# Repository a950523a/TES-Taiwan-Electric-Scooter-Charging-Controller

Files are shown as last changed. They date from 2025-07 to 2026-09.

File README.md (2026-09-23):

# TES-0D-02-01 DC Charger Controller

> 專為 TES-0D-02-01 標準設計的開源電動機車直流充電控制器。  
> 基於 ESP32-S3，使用 ESP-IDF 原生開發，支援 Web UI 監控、REST API 及 OTA 無線更新。






---

> 🛒 **現成品與服務**：iE125 原廠充電器改裝、TES 快充控制板 —— 見 **[海龜電能官網](https://a950523a.github.io/)**。

---

## ⚠️ 免責聲明與安全警告

**本專案僅包含「控制板」的軟硬體設計，不包含功率級電源模組。**

1. **高壓危險**：本控制器需配合高壓直流電源使用，組裝與測試過程存在觸電與火災風險。
2. **非商業產品**：本專案為個人研究與技術驗證性質，未經 BSMI、UL 等安規認證。
3. **責任歸屬**：使用本專案所產生的任何後果（包括但不限於車輛損壞、電池故障、人身傷害），**使用者需自行承擔**。若不具備相關電學知識，請勿嘗試製作。
4. **BMS 風險**：CAN Bus 線路若接線錯誤或短路，**將導致車輛 BMS 永久性損壞**，請務必在低壓環境確認無誤後再上機。

---

## 🎯 專案範圍

本 Repository 專注於 **TES 協議控制邏輯** 的實作。

- **包含**：ESP32-S3 控制韌體、CAN Bus 通訊、狀態機邏輯、Web UI、OTA 更新
- **不包含**：功率級整流器、AC/DC 電源模組的控制碼（請依據選用的電源模組自行適配）

---

## ✨ 功能特點

### 核心協議
- **TES 標準相容**：完整實作 TES-0D-02-01 充電通訊協議（0x500/501/508/509/5F0/5F8）
- **寬範圍支援**：最高支援 120V / 100A (12 kW)
- **通用性**：適用於 eMoving iE125 ZAU ES-2000 等支援 TES 快充標準之車輛

### 智慧功能
- **Web UI / PWA**：內建單頁應用，1 秒即時更新電壓、電流、SOC、剩餘時間；可安裝至手機桌面
- **REST API**：`GET /status`、`POST /start`、`POST /stop`、`POST /ota`
- **mDNS**：連接 WiFi 後可用 `http://tes-charger.local` 直接存取
- **OTA 無線更新**：Web UI 一鍵從 GitHub Releases 拉取最新韌體，自動重刷
- **MQTT 遠端監控**：設定 broker 後可在任何網路環境即時監控並遠端 Start/Stop
- **Cloud PWA**：無需與設備在同一個 WiFi，透過 MQTT 遠端監控 👉 [monitor.html](https://a950523a.github.io/TES-Taiwan-Electric-Scooter-Charging-Controller/monitor.html)
- **推播通知**：充電開始／完成／故障時自動透過 ntfy 或 Webhook 推播到手機
- **充電紀錄**：最近 20 次充電的時長、電量 (Wh)、SOC 起訖、停止原因
- **OLED 狀態顯示**：SSD1306 128×64，顯示充電狀態、電壓電流、SOC、剩餘時間
- **設定選單**：長按 SETTING 進入，可調最大電壓、電流、目標 SOC、WiFi 設定
- **LuxBeacon**：LED SOC 脈衝燈號編碼

### 架構特點（V3 重構）
- **純 C99 狀態機**（`tes_protocol/`）：零平台依賴，可移植至 STM32 或 PC 單元測試
- **HAL 抽象層**：硬體相關程式碼全部隔離在 `charger_hal/` 和 `drivers/`
- **GitHub Actions CI/CD**：推送 tag 自動編譯並建立 Release

---

## 🚀 安裝韌體

### 方法一：瀏覽器一鍵燒錄（推薦，無需安裝任何工具）

使用 Chrome 或 Edge，前往 👉 **[GitHub Pages 燒錄工具](https://a950523a.github.io/TES-Taiwan-Electric-Scooter-Charging-Controller/)**

USB 連接主板，點「開始安裝」，全程自動完成（約 30–60 秒）。

### 方法二：命令列燒錄

從 [Releases](https://github.com/a950523a/TES-Taiwan-Electric-Scooter-Charging-Controller/releases/latest) 下載 `tes_charger_flash.bin`：

```bash
esptool.py --chip esp32s3 -p <PORT> write_flash 0x0 tes_charger_flash.bin
```

### 方法三：OTA 更新（已有 V3 韌體）

連線至設備 Web UI → 點「更新至最新韌體」→ 自動從 GitHub Releases 下載並重刷。

---

## 📶 初次設定 WiFi

燒錄完成後：

1. 用手機或電腦連接 WiFi：`TES-Charger`（無密碼）
2. 瀏覽器開啟 `http://192.168.4.1`
3. 在「設定」填入家用 WiFi SSID 與密碼 → 儲存
4. 重啟後自動連接，之後使用 `http://tes-charger.local`

---

## 📱 遠端監控

### 裝置端 PWA（同一個 WiFi）

連線至 `http://tes-charger.local`，點瀏覽器「加入主畫面」即可安裝為 PWA。

### Cloud PWA（任何網路）

👉 **[https://a950523a.github.io/.../monitor.html](https://a950523a.github.io/TES-Taiwan-Electric-Scooter-Charging-Controller/monitor.html)**

需先在裝置端 Web UI 設定 MQTT Broker（建議使用免費公共 broker：`mqtt://broker.hivemq.com:1883`）。
設定後點「取得遠端監控連結」，掃描 QR code 或複製連結，在任何地點開啟即可即時監控並遠端 Start/Stop。

---

## 🕹️ 操作說明

| 按鈕 | 待機 | 選單導覽 | 選單編輯 |
|---|---|---|---|
| START | 開始充電 | 上一項 | 微調 +0.1 / 長按 +1 |
| STOP | 停止充電 | 下一項 | 微調 −0.1 / 長按 −1 |
| SETTING 短按 | 循環 SOC 預設 (80→95→100%) | 確認 / 進入編輯 | 確認，回到導覽 |
| SETTING 長按 | 開啟設定選單 | — | — |
| EMERGENCY | 緊急停止（任何狀態有效） | 同左 | 同左 |

---

## 🛠️ 硬體設計

- **原理圖 / PCB**：`docs/PCB/` 目錄
- **BOM**：`docs/BOM_V2/` 目錄
- **主要元件**：ESP32-S3 N16R8、ADS1115、SSD1306 OLED、CAN Transceiver、繼電器模組

硬體設計以通用性為核心，亦適合使用萬用板手工搭建。

---

## 💻 開發環境（ESP-IDF）

```powershell
# 設定環境（Windows）
$env:IDF_PATH = "C:\Users\<user>\esp\v5.5.1\esp-idf"
# 詳見 CLAUDE.md 完整 PATH 設定

# 編譯
cd v3
idf.py build

# 燒錄
idf.py -p <PORT> flash monitor
```

詳細架構說明、任務設計、IPC 機制請參閱 [CLAUDE.md](CLAUDE.md)。

---

## 🤝 社群與支援

- **服務與洽詢**：[海龜電能官網](https://a950523a.github.io/)・[Facebook 粉專](https://www.facebook.com/profile.php?id=61582382523577)（iE125 原廠充電器改裝、TES 快充控制板）
- **Facebook 社群**：[TES 電動機車充電技術交流](https://www.facebook.com/groups/791962053528872/?ref=share&mibextid=NSMWBT)
- **問題回報**：[GitHub Issues](https://github.com/a950523a/TES-Taiwan-Electric-Scooter-Charging-Controller/issues)

---

## ⚖️ 授權

### 著作權

本專案的程式碼與設計檔案採用 **[CC BY-NC-SA 4.0](https://creativecommons.org/licenses/by-nc-sa/4.0/deed.zh_TW)** 授權。

- ✅ 分享與改作：需標示原作者，並以相同條款釋出
- 🚫 禁止商業使用：不得將本專案之設計圖檔、程式碼用於商業量產或販售營利

### 專利權不在本授權範圍內

CC BY-NC-SA 4.0 **只授權著作權，不授權專利權**。這不是本專案額外附加的限制，
而是授權條款本文第 2(b)(2) 節的明文規定（見 [`LICENSE.md`](LICENSE.md) 第 52 行）：

> Patent and trademark rights are not licensed under this Public License.
>
> （本公眾授權條款不授權專利權與商標權。）

因此，依 CC BY-NC-SA 4.0 使用本專案者，僅取得著作權範圍內之授權。**如需商業
使用授權，請另行聯絡作者。**

Copyright (c) 2025-2026 Chris Huang.
All rights not expressly granted under the above license are reserved.

---

## 📌 專案紀錄

| 階段 | 時間 | 內容 |
|---|---|---|
| 專案開始 | 2025-06-19 | Arduino 原型 |
| V2 系列 | 2025-10 ~ 2025-12 | PlatformIO / C++，v2.4.0 ~ v2.5.0-beta |
| **V3 重構** | 2026-05-02 | 改用 ESP-IDF 原生 C99，協定層抽成零相依模組 |
| 遠端監控 | 2026-05 ~ 2026-09 | MQTT、Cloud PWA、排程充電、ESP-NOW PSU 傳輸 |
| 最新釋出 | 2026-09-10 | v3.5.0，**實車驗證完整充電流程** |
| 硬體 V1.3 | 2026-09 | 由 EasyEDA Pro 遷移至 KiCad，改為工具鏈可重現、可驗證 |

技術範圍涵蓋：TES-0D-02-01 協定狀態機、CAN Bus 通訊、即時 FreeRTOS 任務架構、
電源模組控制（UART／ESP-NOW 雙傳輸）、Web UI／REST API／PWA、OTA 更新、
以及 PCB 設計與驗證工具鏈。

作者：**Chris Huang**（[@a950523a](https://github.com/a950523a)）

---

## 🔗 相關專案

- **[TES-Protocol](https://github.com/a950523a/TES-Protocol)**：本專案抽出的可攜式 C99 CAN codec（`tes_types.h` + `tes_codec.c`），可作為 submodule 用於 STM32 或其他平台
- **[LianMing-PSU-Controller](https://github.com/a950523a/LianMing-PSU-Controller)**：聯明電源 CAN Bus 控制器，可與本專案配合使用實現高功率便攜充電方案

---

## 影片

https://youtube.com/shorts/SKAtfQcCqX8?si=aqei7ZD7hVCWWM0R

https://youtu.be/vA7gSdK1YZQ?si=lSQAtU0p7vCutx1Y

## 照片

> 此為專案 V2 早期時所拍的照片，V2 後期轉為自行畫 PCB 並使用 ESP32-S3 開發。

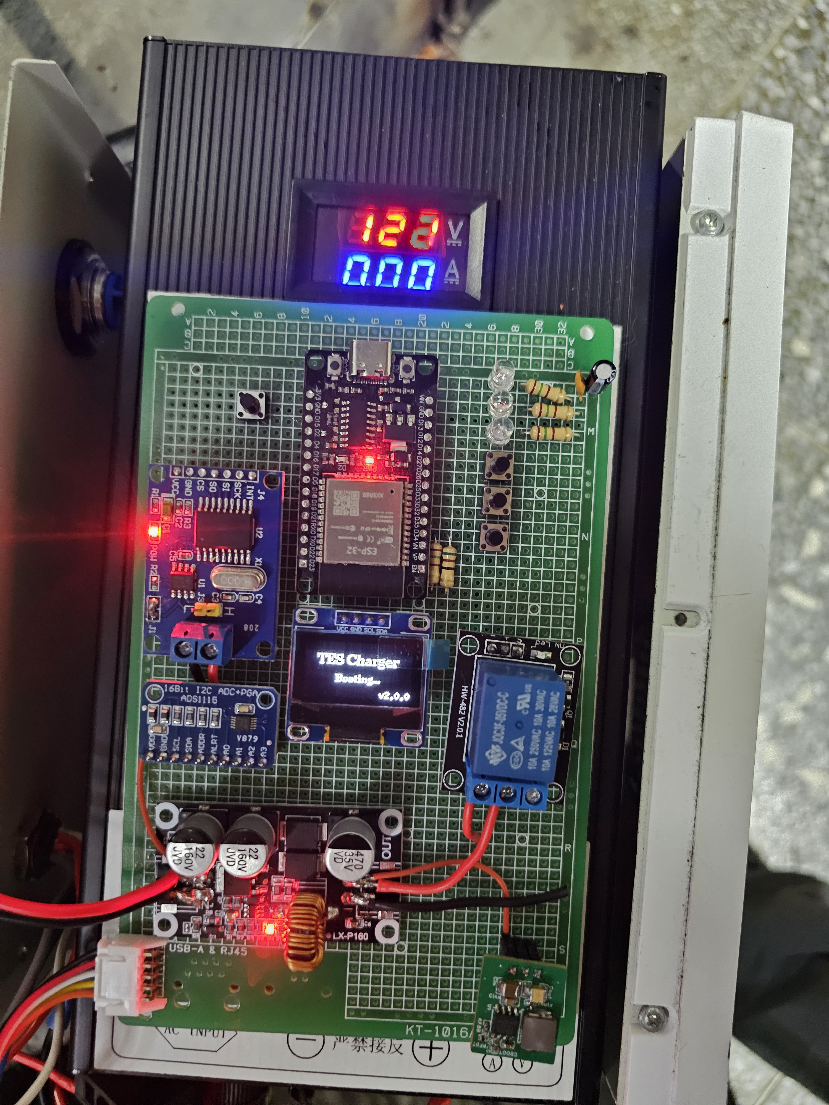
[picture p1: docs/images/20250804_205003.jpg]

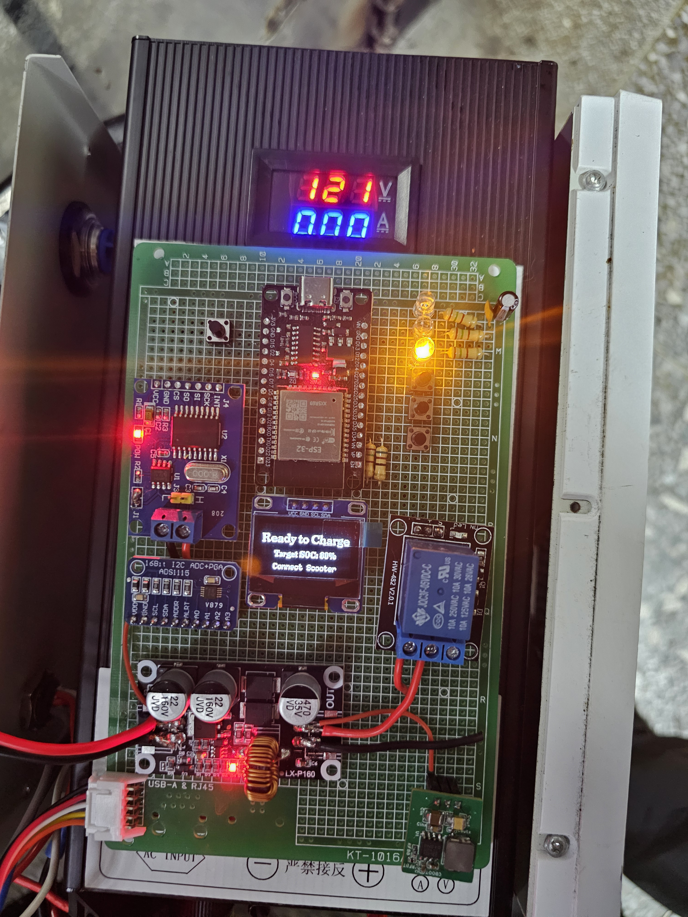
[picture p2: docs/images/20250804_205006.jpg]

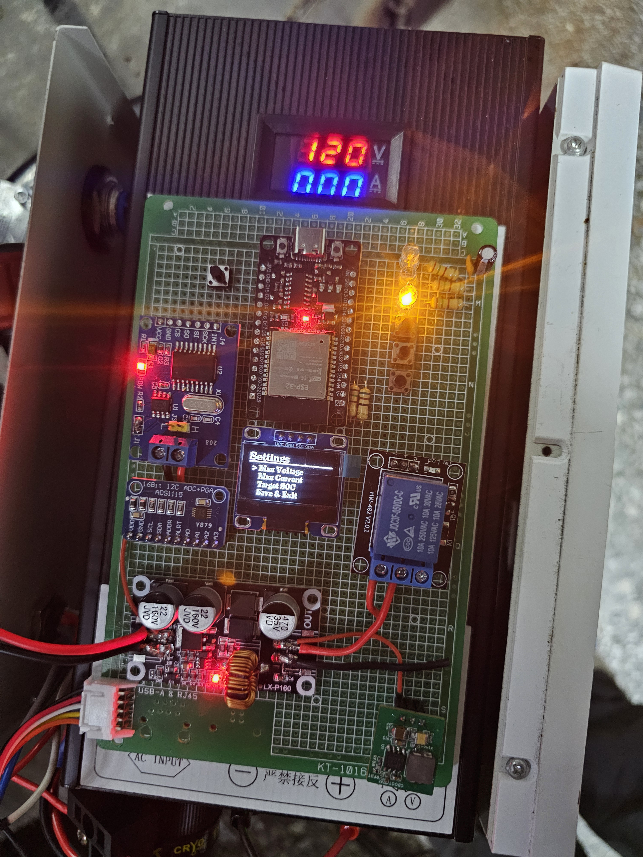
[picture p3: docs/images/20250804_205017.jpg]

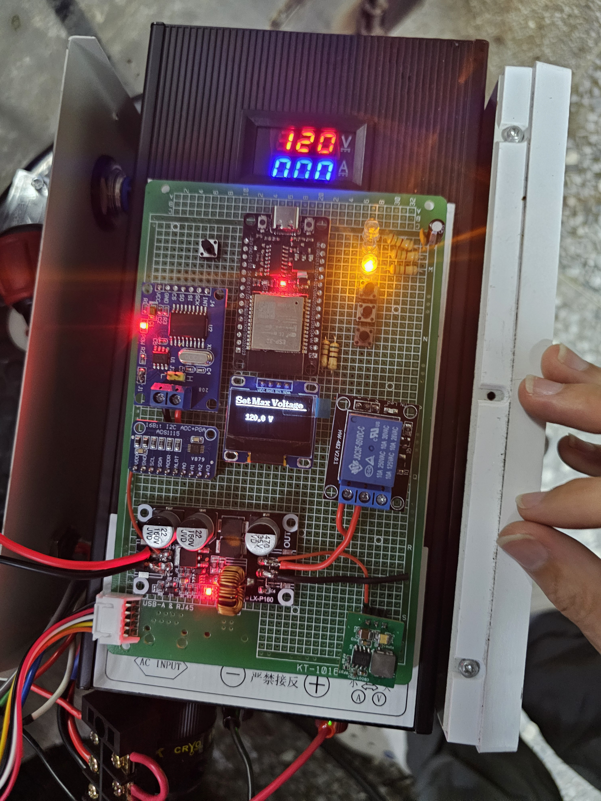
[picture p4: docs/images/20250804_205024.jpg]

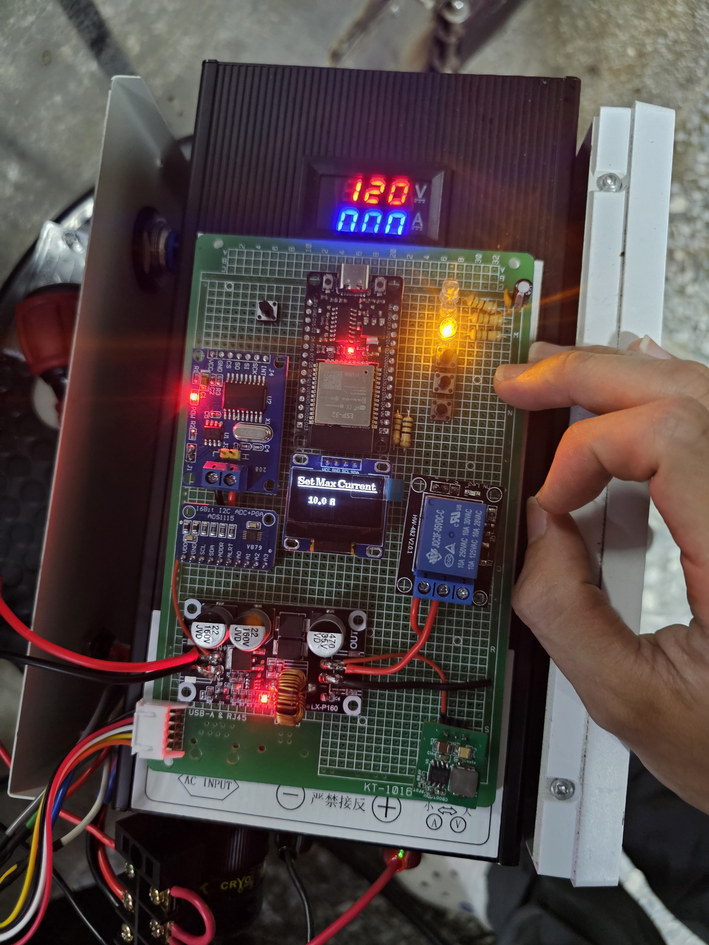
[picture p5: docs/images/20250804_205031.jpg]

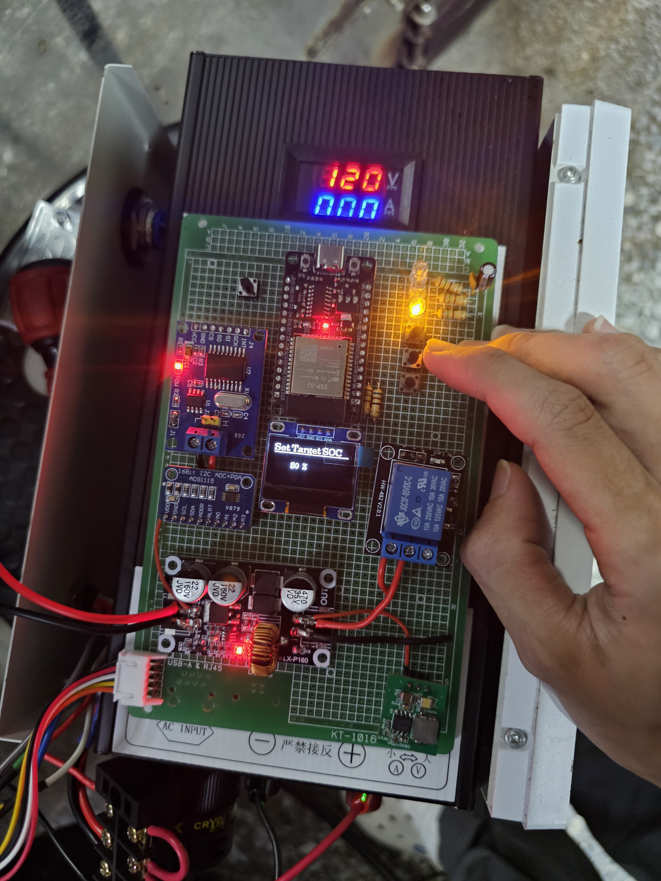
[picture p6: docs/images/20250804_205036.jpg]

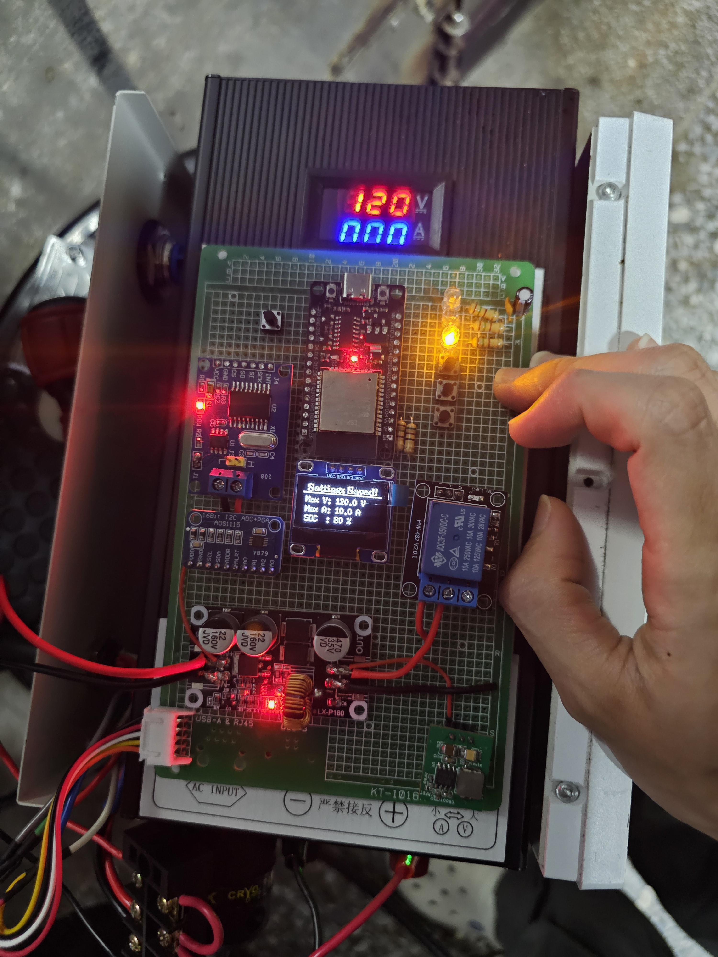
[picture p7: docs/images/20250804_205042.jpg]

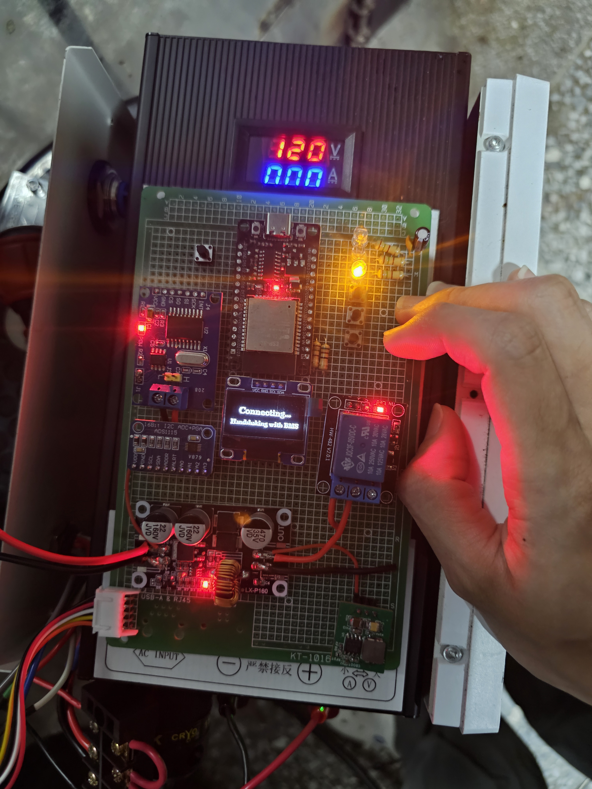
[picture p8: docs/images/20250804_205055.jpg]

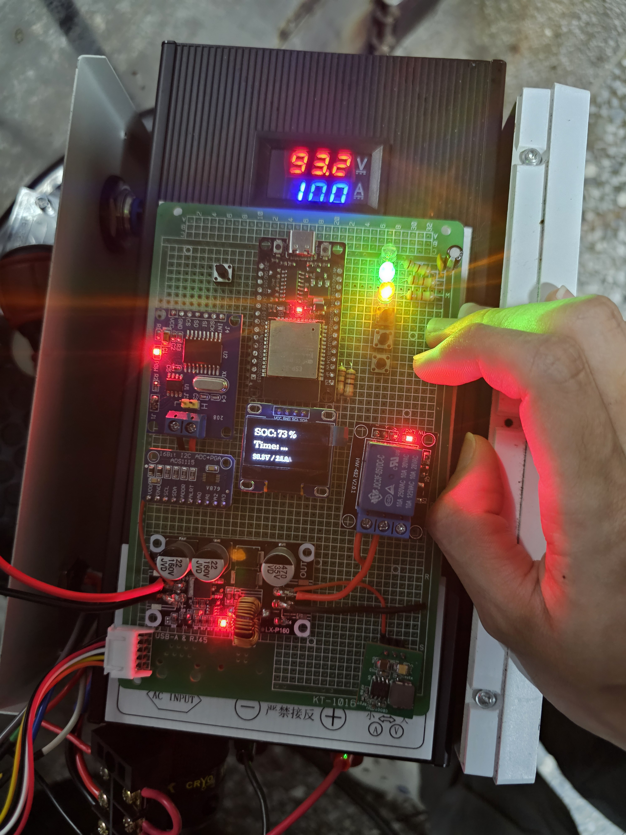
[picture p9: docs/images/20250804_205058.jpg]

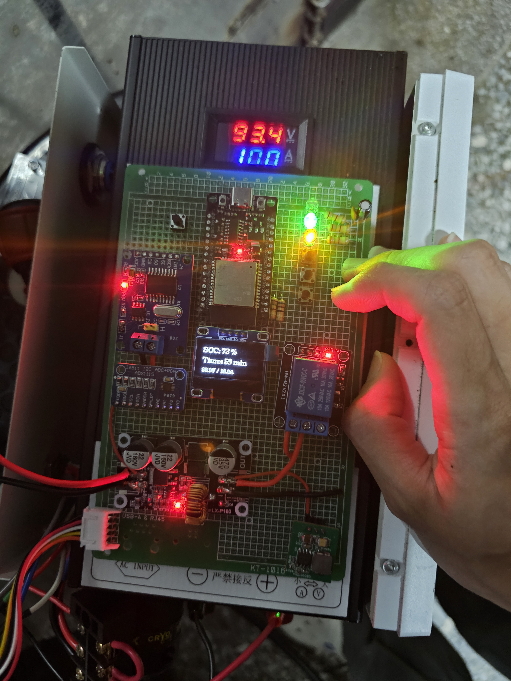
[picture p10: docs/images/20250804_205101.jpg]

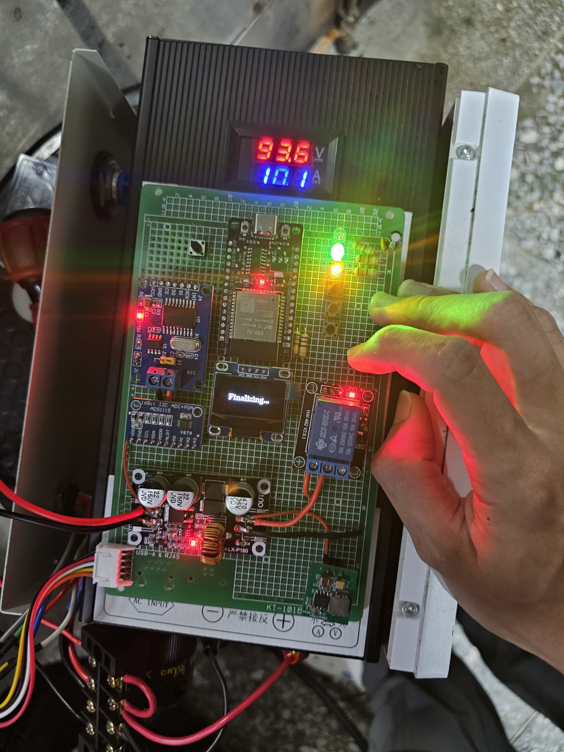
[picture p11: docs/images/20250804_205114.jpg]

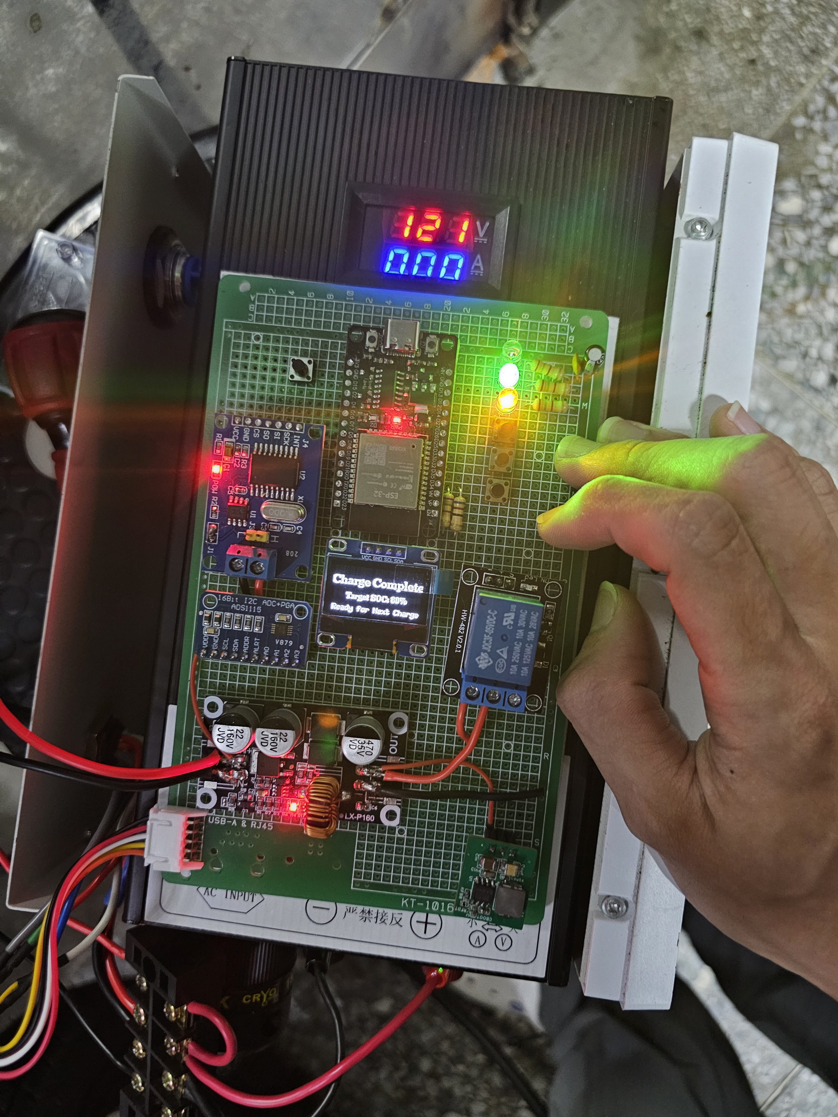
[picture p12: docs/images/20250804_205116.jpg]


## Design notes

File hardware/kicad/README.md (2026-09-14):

# KiCad 專案（已由 EasyEDA Pro 遷移完成，待出圖）

V1.3 起的硬體設計在 KiCad 進行。EasyEDA Pro 的 V1.3 仍保留在
`docs/PCB/`，並由 `tools/eda_export.py` 匯出成可 diff 的文字檔放在
`hardware/TES_Controller_V1.3/`，作為對照基準。

## 目錄

| 路徑 | 內容 | 進版控 |
|---|---|---|
| `lib/TES.kicad_sym` | 45 個符號：34 個由 BOM 的 LCSC 料號產生、4 個沒有料號的自行產生、6 個電源符號加 PWR_FLAG | ✅ |
| `lib/TES.pretty/` | 28 個封裝 | ✅ |
| `lib/TES.3dshapes/` | 42 個 3D 模型（.step + .wrl） | ❌ **39 MB，已 gitignore** |
| `sym-lib-table` / `fp-lib-table` | 專案層級元件庫設定，開啟專案即生效 | ✅ |

3D 模型是純衍生檔，任何時候都能重新抓。不進版控是因為 `.git` 已經 785 MB，
再塞 39 MB 的二進位進去（而且每次更新元件就是一份全新 blob）划不來。

### 重新產生元件庫

```bash
python tools/kicad_lib.py            # 符號 + 封裝 + 3D
python tools/kicad_lib.py --no-3d    # 只要符號 + 封裝（不需要看 3D 時）
```

需要先建好 venv 並安裝 `easyeda2kicad`，指令寫在 `tools/kicad_lib.py` 檔頭。
腳本會把封裝裡的 3D 路徑改成 `${KIPRJMOD}/lib/TES.3dshapes/...`；
easyeda2kicad 產生的是**絕對路徑**，直接提交會在別台機器上全部失效。

## 沒有 LCSC 料號的元件

這幾個在 EasyEDA 用的是內建通用元件，沒有料號可轉。改成由
`tools/make_symbols.py` / `tools/make_footprints.py` 直接產生，留在同一個
`TES` 庫裡，不必混用 KiCad 內建庫：

| 位號 | EasyEDA 元件 | 現在的符號 |
|---|---|---|
| `D6` `D7` `D8` | led_th-r_5mm | `TES:LED-5MM` |
| `H1` | hdr-f_2.54_1x4p | `TES:HDR-1X4` |
| `H2` | hdr-f_2.54_1x3p | `TES:HDR-1X3` |
| `W1`–`W4` | 焊盤 | `TES:SOLDERPAD-1P` |

## 遷移狀態

- [x] 元件庫（符號 / 封裝 / 3D）
- [x] 電路圖 —— Altium 中轉匯入不了；先改成由網表機器排版，再改成
      **照原稿座標重畫**（`tools/sch_import_easyeda.py`），版面和 EasyEDA 一致
- [x] 網表驗證：230 條接線對 V1.3 原始網表**零差異**
- [x] ERC：0 條違規
- [x] PCB layout —— 雙層、單面貼片；底層整片接地銅箔，機構座標未動
- [x] DRC：0 錯誤、0 未連接（尚有 167 條絲印／外框重疊類警告）
- [x] 電氣修正 —— R10 耐壓、ADS1115 I²C 準位、120V 間距、降壓板進出各一顆 TVS
- [ ] Gerber 出圖 —— 還沒做，也還沒下過單

> START 的去彈跳接點不必改：TS-1187A 的 1、2 腳在封裝內部就是短路的，
> 網表裡 START1.3 和 START1.4 也都接 GND，原本以為的問題不存在。

### 全部重新產生

```bash
sh tools/regen_hw.sh            # 含 3D 模型
sh tools/regen_hw.sh --no-3d    # 不抓 3D，快很多
```

八個步驟都是冪等的 —— 但**冪等指的是結果，不是檔案位元組**：符號和導線的
UUID 每次重新產生都是新的，所以重跑一次 `TES_Controller.kicad_sch` 就會出現
兩千多行的 diff，內容其實只有 UUID 不同。要確認有沒有實質變化，跑
`git diff -- hardware/kicad/TES_Controller.kicad_sch | grep -v uuid`，
或乾脆 `git checkout` 掉。

第 4 步會拿 `kicad-cli sch export netlist` 的結果對
`hardware/TES_Controller_V1.3/netlist.txt` 逐條比對，**有任何一條對不上就失敗** ——
這是整條流程的意義所在：轉檔有沒有漏東西是被驗證的，不是用看的。

第 4 步跑的是 `tools/sch_import_easyeda.py`，不是 `tools/sch_gen.py`。後者是早期
「由網表機器排版」的版本，直接跑會把照原稿重畫的版面蓋掉；它現在的角色是
函式庫（載入元件庫、讀網表、驗證），由前者匯入使用。

### 位號變更

KiCad 把沒有結尾數字的位號視為「未編號」，在 GUI 按一次 Annotate 就會被重新命名。
V1.3 有 9 個這種位號，趁重畫改掉：

| V1.3 | 現在 | 說明 |
|---|---|---|
| `Y` `G` `R` | `D6` `D7` `D8` | LED。`R` 若只補數字會變成 `R1`，和既有電阻撞名 |
| `START` `STOP` `SETTING` `EMERGENCY` | 各加 `1` | 絲印可讀性不變 |
| `BOOT` `EN` | `BOOT1` `EN1` | 同上 |

對照表寫在 `tools/sch_gen.py` 的 `DESIGNATOR_RENAME`，比對網表時會換回原名，
所以驗證仍然是對著 V1.3 的原始資料做的。

### V1.3 新增與變更的元件

`tools/changes_v13.py` 是唯一的來源，每一項都附了理由，電路圖和 PCB 都照它套用：
R10 換值並改接 R33、新增 R33/R34（115 k ×3 串聯的上臂）、R11 換 9.09 k、
U5 改回 3.3 V、D9/D10 兩顆 TVS。這些元件在電路圖上另外擺在圖面下方
「V1.3 新增」區，用標籤接線。

### 網路改名

EasyEDA 自動產生的 `$1N24345` 這類網名沒有意義，已改成 `VOUT_SENSE`、`CP_SENSE`、
`VP_PGATE` 等。對照關係在 `tools/sch_gen.py` 的 `NET_RENAME`，每一條都附了推導依據。

匯入完成後跑設計檢查：

```bash
kicad-cli pcb drc --severity-error --exit-code-violations hardware/kicad/TES_Controller.kicad_pcb
```

DRC **不進 CI** —— 設計檢查是設計當下的工作，不是每次 push 都要跑的東西。

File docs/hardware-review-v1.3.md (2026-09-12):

# V1.3 PCB 設計審查

審查日期：2026-09-13 ｜ 對象：`docs/PCB/TES_Controller_V1.3.eprj`（**尚未生產**）
方法：解析 EasyEDA Pro 專案檔，實際量測幾何與網表，無目視檢查。
可用 `python tools/eda_export.py --all` 重現本報告使用的所有資料。

板子：64.1 × 89.3 mm，雙層，兩面整板鋪 GND，73 個位號。

> ### ⚠️ 初版報告有一項錯誤，已更正
> 初版分析的是 `TES_Controller_V1.3_backup/…2026-05-07.zip`，那是**舊快照**。
> 據此指稱「ADS1115 的 VDD 仍接 3.3V、V1.2 的已知問題沒修」——**這是錯的**，
> 當前 `.eprj` 裡 `U5.8 = 5V`，該問題已經修正。
> 本版所有結論皆已對當前 `.eprj` 重新驗證（幾何量測結果與舊快照一致，
> 僅 U5 供電與 H2 接頭有差異）。
> **教訓：`.eprj` 才是當前狀態，備份 zip 只是歷史快照。**

---

## 摘要

| # | 項目 | 結果 |
|---|---|---|
| 1 | **I2C 準位不相容** | 🔴 **需修正** — ADS1115 用 5V 供電，但匯流排只有 3.3V |
| 2 | **120V 網路間距規則** | 🔴 **需修正** — 規則值為 IPC 要求的 38% |
| 3 | ADS1115 量測範圍 | ✅ V1.2 的上限問題已在 V1.3 修正 |
| 4 | 120V 對其他走線的實際間距 | ✅ 1.25 mm |
| 5 | 12V 載流能力 | ✅ 約 2 倍餘裕（電磁鎖電流待定） |
| 6 | ESP32 天線淨空 | ✅ 天線外伸板外 |
| 7 | 去耦電容佈局 | ✅ 全部 ≤ 4.7 mm |
| 8 | USB 差動對 | ✅ 長度差 0.01 mm |
| 9 | GND 鋪銅完整性 | ✅ 大致完整 |
| 10 | AMS1117 散熱 | ⚠️ 帳面可接受，建議實測 |

---

## 🔴 1. I2C 準位不相容（V1.3 新引入）

```
U5.8  = 5V      ← ADS1115 改用 5V 供電（V1.2 是 VDD33）
R5:  SCL ↔ VDD33   ← I2C 上拉仍接 3.3V
R6:  SDA ↔ VDD33
```

ADS1115 規格書（TI SBAS444E §5.5 DIGITAL INPUT/OUTPUT）：

| 參數 | 規格 |
|---|---|
| V_IH 高準位輸入 | **MIN = 0.7 × VDD**，MAX = 5.5 V |
| V_IL 低準位輸入 | GND ~ 0.3 × VDD |

**VDD = 5.0 V → V_IH 最低需 3.5 V，但匯流排高準位只有 3.3 V。**

I2C 是開汲極，所以 ESP32 不會被 5V 打到（**無過壓風險**）；問題是 ADS1115
可能認不出「高」。實際矽片的切換點通常低於保證值，室溫下多半會動——
但這是 −40 ~ +125 °C 全溫域的規格外操作，**而且 V1.3 從未生產過，
這個組態沒有任何實測資料**。

### 為什麼會變成 5V

改 5V 的動機是對的。規格書註(1)：類比輸入不得超過 `VDD + 0.3V`。

| VDD | 類比輸入上限 | 348k/12k 分壓（比例 1/30）可量測到 |
|---|---|---|
| 3.3 V | 3.6 V | 約 108 V ← **低於標稱的 120 V** |
| 5.0 V | 5.3 V | 122.88 V（±4.096V FSR 吃滿）✅ |

所以 V1.2 的 3.3V 配置確實量不到 120 V，改 5V 解決了量測範圍，
**但把問題搬到了 I2C**。

### 兩個解法

| 方案 | 做法 | 評估 |
|---|---|---|
| **A. 回 3.3V + 改分壓** | `U5.8` 接回 `VDD33`，`R11` 12kΩ → **9.1kΩ** | ✅ **建議**。零件數不變、I2C 完全合規 |
| B. 保留 5V + 加準位轉換 | SDA/SCL 加 PCA9306 或 2× BSS138 | 多一顆料與佈線，且 OLED 也在同一條匯流排上 |

**方案 A 的數字**（348kΩ / 9.1kΩ，比例 9.1/357.1 = 0.02548）：

| 輸入 | AIN0 | 狀態 |
|---|---|---|
| 120 V | 3.058 V | ✅ 在 3.3 V 內 |
| 129.5 V | 3.3 V | 量測天花板，對 120 V 標稱有 8% 餘裕 |

解析度不是問題：16-bit ADC 搭 ±4.096V FSR = 125 µV/LSB，換算到輸入端
約 4.9 mV/LSB。

⚠️ 採用方案 A 時，**韌體常數必須同步修改**：
`firmware/components/drivers/include/drivers/adc_driver.h`
`#define ADC_VOLT_R2_KOHM 12.0f` → `9.1f`。
這會造成韌體與硬體版本綁死，見下方「硬體版本識別」。

---

## 🔴 2. 120V 網路的間距規則過寬鬆

```
RULE_SELECTOR：52 個網路全部指定為 class 4（含 120V 與 GND）
safeClearance[4][4] = 6 mil = 0.152 mm
POUR GND layer=1 / layer=2  clearance=0.2
```

底層是整片 GND 鋪銅，**120V 在底層走了 63.9 mm**，鋪銅會沿線填到規則允許的
最近距離。

IPC-2221B 外層導體，101–150 V：

| 條件 | 最小間距 |
|---|---|
| 有防焊層 | **0.4 mm** |
| 無防焊層 | 3.2 mm |

**目前 0.152 mm，只有要求的 38%。** V1.2 → V1.3 規則完全沒有改動。

### 建議修正

1. 建立獨立網路類別（如 `HV`），把 `120V` 指定進去
2. 該類別對其他所有網路的間距設 **≥ 0.4 mm**，建議直接 **0.8–1.0 mm**
3. 重新鋪銅 + 重跑 DRC

> **需目視確認**：本項依規則推論鋪銅行為。EasyEDA 不把鋪銅後的銅箔輪廓
> 存成可解析的幾何，所以請放大 120V 走線，看它與周圍 GND 的實際間隙。

---

## ✅ 3–9. 通過的項目

### 3. ADS1115 量測範圍（V1.2 問題已修）
`U5.8 = 5V`，類比輸入上限 5.3 V，348k/12k 在 120 V 時輸出 4.0 V，
搭配 ±4.096 V FSR 剛好。**量測範圍本身沒問題**，代價見第 1 項。

AIN1 接 `GND_BACK` 而非 `GND` —— 這是 Kelvin 回授，分壓下臂的回流不會
混進量測基準。這個做法值得保留。

CP 分壓 `R9 150Ω / R8 51Ω`，比例 0.2537，CP 12 V → 3.05 V，在範圍內。

### 4. 120V 對其他**走線**的實際間距
最小 **49.3 mil (1.25 mm)**（對 `$1N24345`，同層），遠高於要求。
註：僅走線對走線；鋪銅見第 2 項。

### 5. 12V 載流能力
| 線寬 | 長度 | IPC-2221 載流（1oz 外層 ΔT=10°C） |
|---|---|---|
| 50 mil (1.27 mm) | 106 mm | 2.84 A |
| 30 mil (0.76 mm) | 41 mm | 1.96 A |
| 10 mil | 2.5 mm（兩小段，非主路徑） | 0.89 A |

負載：繼電器線圈 0.5 A × 2 = 1.0 A → 主路徑約 2 倍餘裕。
**電磁鎖電流未知**（尚未選定帶電磁鎖的充電槍料件）。超過 0.9 A 時
30 mil 段需重新評估。

### 6. ESP32 天線淨空
`U1 = ESP32-S3-WROOM-1-N16R8 @ (26.5, 10.3) mm`，**天線端外伸出板外**，
符合 Espressif 建議。

⚠️ pad 28/29/30 = IO35/36/37 是 N16R8 的八線 PSRAM 專用腳，目前正確地空著，
**任何改版都不可佔用**。

### 7. 去耦電容佈局
| 電容 | 網路 | 對應 IC | 距離 |
|---|---|---|---|
| C20 | **5V**↔GND | U5 ADS1115 | 4.0 mm |
| C28 | VDD33↔GND | U12 TJA1051 | 3.8 mm |
| C29 | 5V↔GND | U12 | 4.7 mm |
| C16 / C17 | 5V / 12V | U8 降壓模組 | 3.7 / 4.1 mm |
| C1 / C3 | VDD33↔GND | U1 ESP32 | 模組 3V3 腳側 |

C4、C11、C12、C13、C14、C15 **不是去耦電容**，是按鍵消抖電容
（`IO0`/`IO39`/`IO40`/`IO41`/`EN` ↔ GND），應靠近按鍵而非 IC，位置正確。

### 8. USB 差動對
```
UD+  總長 473.3 mil (12.02 mm)  2 個過孔
UD−  總長 472.7 mil (12.01 mm)  2 個過孔
長度差 0.5 mil (0.01 mm)，線間距 17.1 mil (0.435 mm)，線寬同為 10 mil
```
長度匹配、過孔數對稱、間距一致。遠超 USB 2.0 FS 的需求。

### 9. GND 鋪銅完整性
底層訊號走線總長 636 mm，板面積 5728 mm²。最長的底層網路是
120V (63.9 mm)、12V (63.7 mm)、IO11/IO10/IO9 (約 50 mm)、CANH/CANL (45.7 mm)。
以雙層板而言切割程度不高。

> CANH/CANL 走底層 45.7 mm，回流路徑依賴鋪銅與縫合過孔。
> 目前無異常，但日後若 CAN 不穩，這是檢查點之一。

---

## ⚠️ 10. AMS1117 散熱

```
U6 = AMS1117-3.3 (SOT-223)   5V → 3.3V 線性穩壓
3.3V 負載：ESP32-S3 + TJA1051 + OLED（ADS1115 已改由 5V 供電）
```

| 負載 | 耗散 | SOT-223 θJA 60–90 °C/W 的溫升 |
|---|---|---|
| 0.15 A | 0.26 W | +16 ~ +23 °C |
| 0.25 A | 0.42 W | +25 ~ +38 °C |
| 0.35 A（WiFi 持續發射） | 0.59 W | +36 ~ +53 °C |

常溫下不至於觸發熱保護（約 150 °C），帳面上可接受。
建議實測：WiFi 持續傳輸時量 U6 表面溫度與 3.3 V 軌電壓。

---

## 硬體版本識別（第 1 項的連帶需求）

若採用方案 A（改 R11），韌體的 `ADC_VOLT_R2_KOHM` 必須跟著改，於是：

| 韌體 | 板子 | 結果 |
|---|---|---|
| 新（9.1） | V1.4 | ✅ |
| 新（9.1） | V1.3 以下 | 🔴 電壓讀值錯 30% |
| 舊（12） | V1.4 | 🔴 同樣錯 30% |

這與「一份韌體支援所有硬體版本、不強迫使用者更新」（見 CLAUDE.md
**Deployment constraints**）直接衝突，**所以韌體必須能辨識自己跑在哪版板子上**。

| 方式 | 腳位成本 | 可區分版本 | 備註 |
|---|---|---|---|
| **I2C EEPROM**（24AA02 等） | 0（掛現有 I2C） | 無限 | 還能存序號與**每台的分壓校正值**，順帶解決電阻公差問題 |
| 類比識別電阻 | 1 支 ADC 腳 | 約 8–12 檔 | 最省；ESP32 尚有 IO1/2/3/4/8 可用 |
| 數位跳線 | N 支腳 = 2^N | 2 腳 = 4 版 | 組合數少 |
| eFuse USER_DATA | 0 | 無限 | **不可逆**，燒錯無法挽回 |

舊板（V1.0–V1.3）沒有識別機制，韌體讀不到就套用「舊板預設常數」，
向後相容乾淨。

---

## 待補資料

1. **電磁鎖工作電流** — 影響第 5 項。選定料件後回填。
2. **鋪銅後的實際銅箔間距** — 第 2 項需目視確認。

---

## 整體評價

十項檢查中八項通過，兩項需修正，都是**設定值層級的修改**
（一顆電阻或一條規則），不涉及重新佈局。

以第二片自製 PCB 而言，基本功都做對了：電源分層、去耦就近、高壓低壓分離、
天線外伸、差動對成對走線並做長度匹配、Kelvin 回授量測、PSRAM 專用腳正確保留。
V1.2 → V1.3 也確實修掉了量測範圍的問題。

審查過程中有四次初步判斷為「可能有問題」，查證後全是誤判
（120V 線寬其實是感測線、120V 走線間距其實充裕、被標紅的去耦電容其實是
按鍵消抖電容、ADS1115 的 VDD 其實已經修好）。**實際設計比初看嚴謹得多。**

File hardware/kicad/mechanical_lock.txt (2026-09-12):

板框 64.14 × 89.32 mm，4 條線段

板框線段 (mm)
  (   0.000,    0.000) → (  64.135,    0.000)
  (  64.135,    0.000) → (  64.135,   89.318)
  (  64.135,   89.318) → (   0.000,   89.318)
  (   0.000,   89.318) → (   0.000,    0.000)

安裝孔 (mm)
  H1  (   7.961,   40.219)  Ø3.20
  H2  (  56.461,   40.219)  Ø3.20
  H3  (   7.961,   64.219)  Ø3.20
  H4  (  56.461,   64.219)  Ø3.20
  孔距 48.50 × 24.00 mm

位號             X(mm)     Y(mm)     旋轉 層     外殼用途
CN1            7.620    74.422    0.0 top   底部連接器 VP
CN2           18.796    80.137  180.0 top   底部連接器 CAN/CP
CN3           56.769    85.852    0.0 top   底部連接器 DC_RELAY
CN5           49.022    85.852    0.0 top   底部連接器 DC_RELAY
CN6           41.021    85.852    0.0 top   底部連接器 COUPLER
D6             8.224     6.315  180.0 top   LED 黃（V1.3 原位號 Y）
D7             8.246    13.300  180.0 top   LED 綠（V1.3 原位號 G）
D8             8.373    20.158  180.0 top   LED 紅（V1.3 原位號 R）
EMERGENCY1    53.649    23.271  270.0 top   按鍵 緊急停止
H1            26.543    22.352  180.0 top   OLED 排針（面板開窗）
SETTING1      44.675    14.441  270.0 top   按鍵 設定
START1        44.675     5.550  270.0 top   按鍵 開始
STOP1         44.675    23.271  270.0 top   按鍵 停止
U1            26.543    10.287    0.0 top   ESP32-S3 模組（天線突出板外）
U10           31.623    86.233    0.0 top   120V 量測輸入端子（DG301 5.0mm 螺絲端子）
USB1          58.811     9.662  270.0 top   Type-C 接頭（側面開孔）
W1             2.663    53.211    0.0 top   模組 IN 側 120V 焊盤
W2            61.595    53.211    0.0 top   模組 OUT 側 12V 焊盤
W3             2.663    57.211    0.0 top   模組 IN 側 GND_BACK 焊盤
W4            61.595    57.211    0.0 top   模組 OUT 側 GND 焊盤

→ hardware/kicad/mechanical_lock.json

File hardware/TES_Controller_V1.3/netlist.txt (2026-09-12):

BOOT       pad 1    IO0
BOOT       pad 2    GND
C1         pad 1    GND
C1         pad 2    VDD33
C2         pad 1    GND
C2         pad 2    EN
C3         pad 1    GND
C3         pad 2    VDD33
C4         pad 1    EN
C4         pad 2    GND
C7         pad 1    $1N24313
C7         pad 2    GND
C8         pad 1    GND_BACK
C8         pad 2    $1N24345
C9         pad 1    5V
C9         pad 2    GND
C10        pad 1    VDD33
C10        pad 2    GND
C11        pad 1    GND
C11        pad 2    IO0
C12        pad 1    IO39
C12        pad 2    GND
C13        pad 1    $1N24383
C13        pad 2    GND
C14        pad 1    IO40
C14        pad 2    GND
C15        pad 1    IO41
C15        pad 2    GND
C16        pad 1    GND
C16        pad 2    5V
C17        pad 1    GND
C17        pad 2    12V
C20        pad 1    5V
C20        pad 2    GND
C28        pad 1    GND
C28        pad 2    VDD33
C29        pad 1    5V
C29        pad 2    GND
CN1        pad 1    GND
CN1        pad 2    VP
CN2        pad 1    CANL
CN2        pad 2    CANH
CN2        pad 3    GND
CN2        pad 4    CP
CN3        pad 1    12V
CN3        pad 2    DC_RELAY
CN5        pad 1    12V
CN5        pad 2    DC_RELAY
CN6        pad 1    12V
CN6        pad 2    COUPLER
D1         pad 1    12V
D1         pad 2    DC_RELAY
D3         pad 1    VP
D3         pad 2    GND
D4         pad 1    12V
D4         pad 2    COUPLER
D5         pad 1    UD+
D5         pad 2    GND
D5         pad 3    UD-
D5         pad 4    $1N38324
D5         pad 5    VBUS
D5         pad 6    $1N38322
EMERGENCY  pad 1    (未接)
EMERGENCY  pad 2    IO40
EMERGENCY  pad 3    GND
EMERGENCY  pad 4    GND
EN         pad 1    GND
EN         pad 2    EN
G          pad 1    IO6
G          pad 2    $1N24269
H1         pad 1    GND
H1         pad 2    VDD33
H1         pad 3    SCL
H1         pad 4    SDA
H2         pad 1    GND
H2         pad 2    TXD0
H2         pad 3    RXD0
Q1         pad 1    GND
Q1         pad 2    $3N445
Q1         pad 3    DC_RELAY
Q2         pad 1    GND
Q2         pad 2    $1N35540
Q2         pad 3    $1N35533
Q3         pad 1    GND
Q3         pad 2    $3N451
Q3         pad 3    COUPLER
Q4         pad 1    $1N35533
Q4         pad 2    12V
Q4         pad 3    VP
R          pad 1    IO7
R          pad 2    $1N24273
R1         pad 1    VDD33
R1         pad 2    EN
R2         pad 1    GND
R2         pad 2    $1N24295
R3         pad 1    GND
R3         pad 2    $1N24443
R5         pad 1    SCL
R5         pad 2    VDD33
R6         pad 1    SDA
R6         pad 2    VDD33
R8         pad 1    $1N24313
R8         pad 2    GND
R9         pad 1    CP
R9         pad 2    $1N24313
R10        pad 1    $1N24345
R10        pad 2    120V
R11        pad 1    GND_BACK
R11        pad 2    $1N24345
R12        pad 1    GND
R12        pad 2    $1N24273
R13        pad 1    GND
R13        pad 2    $1N24268
R14        pad 1    GND
R14        pad 2    $1N24269
R16        pad 1    IO9
R16        pad 2    $1N35540
R17        pad 1    GND
R17        pad 2    $1N35540
R19        pad 1    IO11
R19        pad 2    $3N445
R20        pad 1    GND
R20        pad 2    $3N445
R21        pad 1    CANH
R21        pad 2    CANL
R26        pad 1    $1N35533
R26        pad 2    12V
R28        pad 1    GND
R28        pad 2    $3N451
R29        pad 1    IO10
R29        pad 2    $3N451
R30        pad 1    $1N38324
R30        pad 2    D-
R31        pad 1    $1N38322
R31        pad 2    D+
R32        pad 1    VDD33
R32        pad 2    IO0
SB1        pad 1    VBUS
SB1        pad 2    5V
SETTING    pad 1    (未接)
SETTING    pad 2    IO41
SETTING    pad 3    GND
SETTING    pad 4    GND
START      pad 1    IO42
START      pad 2    $1N24383
START      pad 3    GND
START      pad 4    GND
STOP       pad 1    (未接)
STOP       pad 2    IO39
STOP       pad 3    GND
STOP       pad 4    GND
U1         pad 1    GND
U1         pad 2    VDD33
U1         pad 3    EN
U1         pad 4    (未接)
U1         pad 5    IO5
U1         pad 6    IO6
U1         pad 7    IO7
U1         pad 8    SCL
U1         pad 9    SDA
U1         pad 10   IO17
U1         pad 11   IO18
U1         pad 12   (未接)
U1         pad 13   D-
U1         pad 14   D+
U1         pad 15   (未接)
U1         pad 16   (未接)
U1         pad 17   IO9
U1         pad 18   IO10
U1         pad 19   IO11
U1         pad 20   (未接)
U1         pad 21   (未接)
U1         pad 22   (未接)
U1         pad 23   (未接)
U1         pad 24   (未接)
U1         pad 25   (未接)
U1         pad 26   (未接)
U1         pad 27   IO0
U1         pad 28   (未接)
U1         pad 29   (未接)
U1         pad 30   (未接)
U1         pad 31   (未接)
U1         pad 32   IO39
U1         pad 33   IO40
U1         pad 34   IO41
U1         pad 35   IO42
U1         pad 36   RXD0
U1         pad 37   TXD0
U1         pad 38   (未接)
U1         pad 39   (未接)
U1         pad 40   GND
U1         pad 41   GND
U1         pad 41   GND
U1         pad 41   GND
U1         pad 41   GND
U1         pad 41   GND
U1         pad 41   GND
U1         pad 41   GND
U1         pad 41   GND
U1         pad 41   GND
U5         pad 1    GND
U5         pad 2    (未接)
U5         pad 3    GND
U5         pad 4    $1N24345
U5         pad 5    GND_BACK
U5         pad 6    $1N24313
U5         pad 7    GND
U5         pad 8    5V
U5         pad 9    SDA
U5         pad 10   SCL
U6         pad 1    GND
U6         pad 2    VDD33
U6         pad 3    5V
U6         pad 4    VDD33
U8         pad 1    GND
U8         pad 2    GND
U8         pad 3    12V
U8         pad 4    12V
U8         pad 5    (未接)
U8         pad 6    5V
U8         pad 7    5V
U8         pad 8    (未接)
U8         pad 9    (未接)
U8         pad 10   (未接)
U8         pad 11   GND
U10        pad 1    120V
U10        pad 2    GND_BACK
U12        pad 1    IO17
U12        pad 2    GND
U12        pad 3    5V
U12        pad 4    IO18
U12        pad 5    VDD33
U12        pad 6    CANL
U12        pad 7    CANH
U12        pad 8    GND
USB1       pad 1    GND
USB1       pad 2    GND
USB1       pad 3    GND
USB1       pad 4    GND
USB1       pad A1B12 GND
USB1       pad A4B9 VBUS
USB1       pad A5   $1N24295
USB1       pad A6   UD+
USB1       pad A7   UD-
USB1       pad A8   (未接)
USB1       pad B1A12 GND
USB1       pad B4A9 VBUS
USB1       pad B5   $1N24443
USB1       pad B6   UD+
USB1       pad B7   UD-
USB1       pad B8   (未接)
W1         pad 1    120V
W2         pad 1    12V
W3         pad 1    GND_BACK
W4         pad 1    GND
Y          pad 1    IO5
Y          pad 2    $1N24268

# 依網路彙整
$1N24268       R13.2  Y.2
$1N24269       G.2  R14.2
$1N24273       R.2  R12.2
$1N24295       R2.2  USB1.A5
$1N24313       C7.1  R8.1  R9.2  U5.6
$1N24345       C8.2  R10.1  R11.2  U5.4
$1N24383       C13.1  START.2
$1N24443       R3.2  USB1.B5
$1N35533       Q2.3  Q4.1  R26.1
$1N35540       Q2.2  R16.2  R17.2
$1N38322       D5.6  R31.1
$1N38324       D5.4  R30.1
$3N445         Q1.2  R19.2  R20.2
$3N451         Q3.2  R28.2  R29.2
120V           R10.2  U10.1  W1.1
12V            C17.2  CN3.1  CN5.1  CN6.1  D1.1  D4.1  Q4.2  R26.2  U8.3  U8.4  W2.1
5V             C9.1  C16.2  C20.1  C29.1  SB1.2  U5.8  U6.3  U8.6  U8.7  U12.3
CANH           CN2.2  R21.1  U12.7
CANL           CN2.1  R21.2  U12.6
COUPLER        CN6.2  D4.2  Q3.3
CP             CN2.4  R9.1
D+             R31.2  U1.14
D-             R30.2  U1.13
DC_RELAY       CN3.2  CN5.2  D1.2  Q1.3
EN             C2.2  C4.1  EN.2  R1.2  U1.3
GND            BOOT.2  C1.1  C2.1  C3.1  C4.2  C7.2  C9.2  C10.2  C11.1  C12.2  C13.2  C14.2  C15.2  C16.1  C17.1  C20.2  C28.1  C29.2  CN1.1  CN2.3  D3.2  D5.2  EMERGENCY.3  EMERGENCY.4  EN.1  H1.1  H2.1  Q1.1  Q2.1  Q3.1  R2.1  R3.1  R8.2  R12.1  R13.1  R14.1  R17.1  R20.1  R28.1  SETTING.3  SETTING.4  START.3  START.4  STOP.3  STOP.4  U1.1  U1.40  U1.41  U1.41  U1.41  U1.41  U1.41  U1.41  U1.41  U1.41  U1.41  U5.1  U5.3  U5.7  U6.1  U8.1  U8.11  U8.2  U12.2  U12.8  USB1.1  USB1.2  USB1.3  USB1.4  USB1.A1B12  USB1.B1A12  W4.1
GND_BACK       C8.1  R11.1  U5.5  U10.2  W3.1
IO0            BOOT.1  C11.2  R32.2  U1.27
IO10           R29.1  U1.18
IO11           R19.1  U1.19
IO17           U1.10  U12.1
IO18           U1.11  U12.4
IO39           C12.1  STOP.2  U1.32
IO40           C14.1  EMERGENCY.2  U1.33
IO41           C15.1  SETTING.2  U1.34
IO42           START.1  U1.35
IO5            U1.5  Y.1
IO6            G.1  U1.6
IO7            R.1  U1.7
IO9            R16.1  U1.17
RXD0           H2.3  U1.36
SCL            H1.3  R5.1  U1.8  U5.10
SDA            H1.4  R6.1  U1.9  U5.9
TXD0           H2.2  U1.37
UD+            D5.1  USB1.A6  USB1.B6
UD-            D5.3  USB1.A7  USB1.B7
VBUS           D5.5  SB1.1  USB1.A4B9  USB1.B4A9
VDD33          C1.2  C3.2  C10.1  C28.2  H1.2  R1.1  R5.2  R6.2  R32.1  U1.2  U6.2  U6.4  U12.5
VP             CN1.2  D3.1  Q4.3

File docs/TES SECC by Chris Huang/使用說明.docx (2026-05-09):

TES 直流充電控制器 (智慧高功率版) V1 - 使用說明書

型號：TES SECC by Chris Huang V1.1 V1.2
韌體版本：V3.0.0

【極重要】安全警告與免責聲明

在開箱、安裝或使用本產品前，請您務必仔細閱讀並完全理解以下所有條款。您的任何使用行為，即構成您對本協議所有條款的完全接受與同意，並自願承擔所有相關風險與責任。

- 高壓危險：本產品涉及高壓直流電，不正確的安裝或操作可能導致觸電、火災或設備損壞。使用者必須具備合格的電子電工知識。
- 非安規認證：本產品為開源專案產品，未經 BSMI 等強制性安規認證，僅供個人實驗與研究使用，嚴禁作為商業成品轉售或在公共場合提供充電服務。
- 責任豁免：在法律允許的最大範圍內，對於因使用本產品而導致的任何直接或間接損害，作者 Chris Huang (a950523a) 不承擔任何形式的法律責任。
- 使用者必須具備 TES 通訊協議之專業知識：本產品透過深度解析 TES-0D-02-01 通訊協議以實現充電控制。使用者必須充分理解其交握流程、安全機制及潛在風險。不正確的設定或使用，可能導致車輛或充電設備損壞。
- 詳細內容請參閱隨附的 免責聲明 及 原理說明 檔案，請閱讀完畢再使用本套件。
- 本套件為開源專案，操作模式及功能可能會隨著韌體更新而不同，請在每次韌體更新前自行上Github專案的Release中查看更新說明

一、 套件開箱與內容物檢查

感謝您選擇我的套件！開箱後，請確認您收到了以下所有物品：

- TES 直流充電控制器主機 x 1

二、 產品接口與功能說明

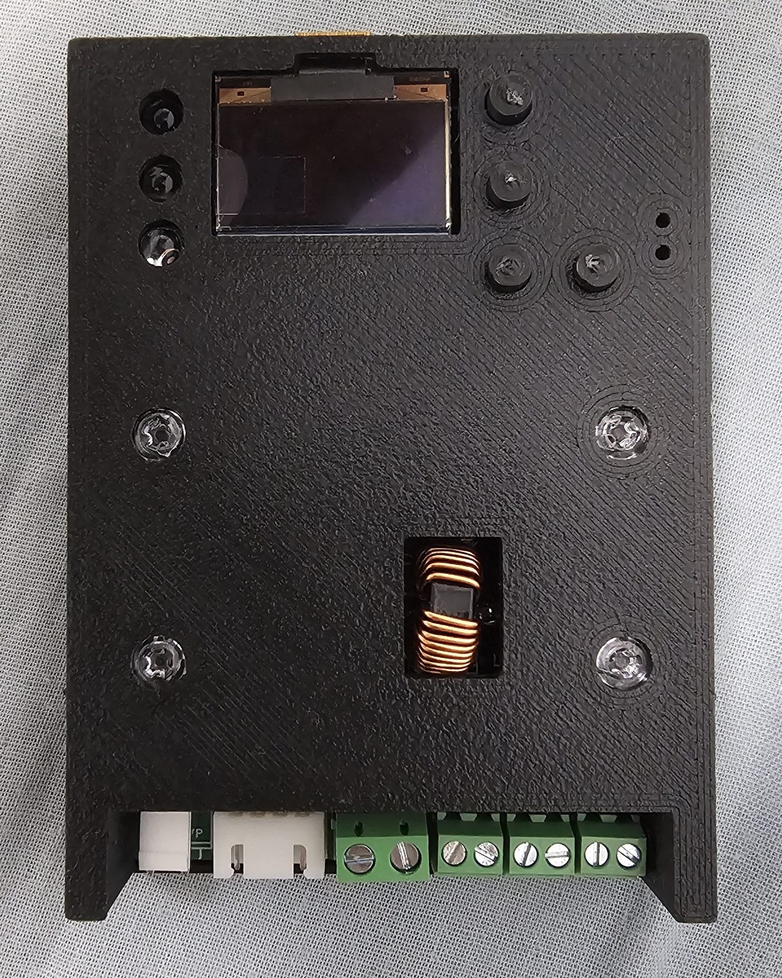
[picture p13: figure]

2-1

2-2

2-3

3-1

4-2

GD/VP

4-2

D-/D+/GND/CP

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
1. OLED 顯示螢幕：顯示實時充電狀態、設定選單等資訊。
2. 狀態指示燈 (LED)：
  1. 橘燈：待機 / 電源指示。
  2. 綠燈：充電中 (閃爍) / 充電完成 (常亮)。
  3. 紅燈：故障 / 異常 (常亮)。
3. 操作按鈕：
  1. START / UP (上)：開始充電 / 在選單中向上移動。
  2. SETTING (設定)：在主畫面時短按循環目標 SOC / 長按進入設定選單 / 在設定選單中短按確認、長按返回。
  3. STOP / DOWN (下)：停止充電 / 在選單中向下移動。
  4. EMERGENCY：緊急停止
4. 接口：
  1. DC 主電源輸入：主電源輸入接口。(DC120V MAX)
  2. 充電槍控制訊號：連接至充電槍的控制線束接口(和iE/勁炫 原廠大充一樣，但還是推薦檢查一下) (VP, GD, CP, CANH(D+), CANL(D-))。
  3. 12V電磁閥控制輸出：用於控制充電槍上的鎖定電磁閥
  4. 12V直流接觸器控制輸出：用於控制外部直流接觸器的訊號輸出。
  5. USB-C (位於側邊)：用於首次韌體燒錄或緊急除錯，日常使用無需連接。

三、 首次安裝與設定

步驟 1：硬體接線 (請在完全斷電的情況下進行！)

1. 將您的直流電源供應器的電源輸出，連接到本機的 DC 120V IN 接口。
2. 將本機的 直流接觸器控制 輸出，連接到您的直流接觸器的線圈控制端(低功率可不安裝(iE/勁炫))。
3. 將您的充電槍控制線束，正確地連接到本機的 充電槍控制訊號 接口。
4. 仔細檢查所有接線是否正確、牢固，特別是正負極性。

【極重要】步驟 2：首次供電能力設定 (OLED)

為確保安全，您必須先透過 OLED 將本控制器的設定與您的電源供應器能力完全匹配！

1. 首次通電：接通電源後，OLED 短暫顯示開機畫面，接著進入待機主畫面。

- 若已開啟「Auto Volt（自動電壓）」功能，開機時會自動讀取當前輸入電壓並暫時套用為最大電壓（不寫入記憶體，僅本次有效）。

2. 預設設定：出廠預設最大電壓 100.0V、最大電流 10.0A、充電停止模式 SOC、目標 SOC 100%。

3. 進入設定選單：在 OLED 主畫面，長按 SETTING 按鈕進入設定主選單。

4. 操作方式（V3 調整邏輯與 V2 不同，請注意）：

- 使用 START (↑) / STOP (↓) 瀏覽選單項目。

- 短按 SETTING 進入編輯模式。

- 進入編輯模式後：

- 短按 START / STOP：微調（±0.1V / ±0.1A / ±1%）

- 長按 START / STOP：粗調（±1V / ±1A / ±5%，持續按住自動連續調整）

- 再次短按 SETTING 確認修改，返回瀏覽模式。

5. 必要設定：請將「Max Voltage」及「Max Current」調整為與您電源供應器輸出相符的數值。

6. 儲存並退出：瀏覽至「Save & Exit」，短按 SETTING 確認儲存。若不想儲存，選「Cancel」離開。

▎完整設定選單項目請參閱第七章「OLED 螢幕畫面詳解」。

步驟 3：Wi-Fi 設定（可選）

V3 韌體所有功能均可在 AP 模式下使用，連接家用 Wi-Fi 後可額外獲得 OTA 線上自動更新及 MQTT 遠端監控功能。

1. AP（熱點）模式：未設定 Wi-Fi 時，通電後自動進入 AP 模式。

2. 連接熱點：在手機或電腦搜尋名為 TES-Charger 的 Wi-Fi 熱點（免密碼，直接連線），並連接。

3. 訪問 Web UI：連線後，開啟瀏覽器訪問 http://192.168.4.1 或 http://tes-charger.local。

4. 設定 Wi-Fi：在 Web UI 的「WiFi 設定」區塊，點擊「掃描」選擇您家中的 Wi-Fi，輸入密碼後點擊「儲存並重啟」。

5. STA（客戶端）模式：裝置重啟後自動連接家用 Wi-Fi。之後可透過 http://tes-charger.local 訪問 Web UI（無需查詢 IP）。

▎ 提示：tes-charger.local 在 AP 與 STA 兩種模式均有效，建議以此作為固定存取網址。

四、充電停止模式

V3 韌體提供三種充電自動停止條件，可依需求選擇：

模式 | 停止條件 | 適用情境
依SOC(預設) | 電池 SOC 達到目標值時停止 | 日常充電，精準控制充電電量
依電壓 | 輸出電壓達到設定值時停止 | 車輛MCU故障需控制充電電壓上限時
依時間 | 充電時間達到設定上限時停止 | 想限制充電時間、半夜定時停止等

設定方式（OLED 或 Web UI 均可）：

在 OLED 設定選單中，選擇「Stop Mode」，短按 SETTING 依序切換（SOC → Volt → Timer → SOC）。選定模式後，對應的參數項目會自動出現：

- SOC 模式 → 設定「Target SOC」（20–100%）

- Volt 模式 → 設定「Stop Voltage」（40.0–120.0V）

- Timer 模式 → 設定「Charge Timer」（1–600 分鐘）

儲存設定後，下次充電即自動依選定條件停止。

【快速 SOC 切換】 在 OLED 主畫面（未開啟選單時），短按 SETTING 可快速循環切換目標 SOC：80% → 95% → 100% → 80%。

五、日常操作

1. 透過 OLED 和按鈕操作

按鈕 | 主畫面(選單關閉) | 選單瀏覽中 | 選單編輯中
START | 開始充電 | 向上移動 | 微調 +0.1（長按：粗調 +1，持續自動連按）
STOP | 停止充電 | 向下移動 | 微調 -0.1（長按：粗調 -1，持續自動連按）
SETTING 短按 | 快速切換目標 SOC | 確認/進入編輯 | 確認修改，返回瀏覽
SETTING 長按 | 開啟設定選單 | — | —
EMERGENCY | 緊急停止（不受選單狀態影響，立即執行） | 同左 | 同左

- 充電：插好充電槍後，按 START 按鈕開始充電。

- 停止：充電中按 STOP 按鈕。務必等充電完全停止後才拔除充電槍，嚴禁在充電中強行拔槍。

- 緊急停止復歸：

- 由實體 EMERGENCY 按鈕觸發：需手動復歸——進入設定選單，選擇「Reset Fault」確認。

- 由車輛 CAN 訊號觸發（如充電完成後車輛發出的信號）：裝置將自動於 5 秒後恢復待機，無需手動操作。

2. 透過 Web UI 遠端操作

在瀏覽器輸入 http://tes-charger.local 開啟 Web UI（詳見第八章）：

- 即時充電數據、遠端 START / STOP。

- 參數設定、充電紀錄查看。

- OTA 韌體更新。

- 推播通知與遠端監控設定。

▎ 注意：OLED 設定選單開啟期間，Web UI 的 START / STOP 按鈕無效。

六、韌體更新 (OTA)

方式一：Web UI 線上自動更新（推薦，需連接 Wi-Fi）

1. 確認裝置已連接可上網的 Wi-Fi。

2. 在 Web UI 的「韌體更新」區塊，點擊「更新至最新韌體」。

3. 裝置自動從 GitHub Releases 下載最新版本，完成後自動重啟。

4. 更新過程中請勿斷電！ 進度可在 Web UI 觀察。

方式二：手動上傳韌體（無需網路連線）

1. 從 GitHub Releases 頁面下載最新的 tes_charger.bin 到您的電腦。

2. 在 Web UI 的「韌體更新」區塊，點擊「上傳韌體」，選擇 .bin 檔案。

3. 上傳完成後裝置自動重啟。

首次燒錄（全新裝置，或從 V2 升級至 V3）

使用 USB-C 連接電腦，前往以下網址，依畫面指示完成一鍵燒錄：

https://a950523a.github.io/TES-Taiwan-Electric-Scooter-Charging-Controller/

▎ 首次燒錄完成後，後續更新均可透過 Web UI 進行，無需再次連接 USB。

七、OLED 螢幕畫面詳解

1. 主畫面（充電中）

充電中的第二、三行顯示格式依充電停止模式而不同：

停止模式 | 第二行 | 第三行
SOC 模式 | 54.2V 12.3A（即時電壓 / 即時電流） | SOC:72/95% 1h23m（即時 SOC / 目標 SOC，已充時間）
Volt 模式 | 54.2V/100.0V（即時電壓 / 目標停止電壓） | SOC:72% 1h23m（SOC 供參考，無目標值；已充時間）
Timer 模式 | 54.2V 12.3A（即時電壓 / 即時電流） | SOC:72% 1h23m/2h00m（SOC 供參考；已充時間 / 目標時長）

2. 設定主選單

長按 SETTING 進入，項目依停止模式動態顯示：

項目 | 說明 | 顯示條件
Auto Volt | 開機自動讀取電壓（ON/OFF） | 常駐
Max Voltage | 最大輸出電壓（40.0–120.0V）；Auto ON 時顯示「V Cap」 | 常駐
Max Current | 最大輸出電流（1.0–100.0A） | 常駐
Stop Mode | 充電停止模式（SOC / Volt / Timer） | 常駐
Target SOC | 目標 SOC（20–100%） | Stop Mode = SOC
Stop Voltage | 停止電壓（40.0–120.0V） | Stop Mode = Volt
Charge Timer | 計時時長（1–600 分鐘） | Stop Mode = Timer
LuxBeacon | LED 燈號功能（ON/OFF） | 常駐
WiFi Info | 顯示目前 IP 位址（唯讀） | 常駐
Reset Fault | 手動復歸緊急停止狀態 | 常駐
About | 顯示韌體版本與作者（唯讀） | 常駐
Save & Exit | 儲存所有設定並退出選單 | 常駐
Cancel | 放棄修改並退出選單 | 常駐

八、Web UI 介面詳解

V3 Web UI 為可安裝的 PWA，建議在手機瀏覽器中點選「加入主畫面」，方便日後快速開啟。

充電狀態

- 即時顯示：充電狀態、電壓、電流、SOC、功率（W）、本次累積電量（Wh）。

- 電壓與 SOC 欄位顯示格式依停止模式切換：

- SOC 模式：電壓顯示單值；SOC 欄顯示「即時 / 目標」（如 72% / 95%）。

- Volt 模式：電壓欄顯示「即時 / 目標停止電壓」（如 54.2 V / 100.0 V）；SOC 欄僅顯示即時值（供參考）。

- Timer 模式：電壓、SOC 均顯示單一即時值（供參考）。

充電控制

- 遠端 START / STOP 按鈕。

- 充電停止模式切換，以及對應的目標 SOC / 停止電壓 / 計時時長設定。

基本設定

- 自動電壓（Auto Volt）、最大電壓、最大電流、LuxBeacon LED開關。

- WiFi 掃描：點擊「掃描」可列出附近熱點，點選即自動填入 SSID。

推播通知（可選）

- ntfy.sh 模式：自動產生隨機 Topic，提供訂閱連結與 Android/iOS App 下載連結，可發送測試推播。

- 自定義 Webhook：直接輸入任意 URL（如 Discord Webhook、自建服務等）。

- 觸發時機：充電開始、充電完成、充電故障、緊急停止。

- 留空則停用推播。

遠端監控（可選，需 Wi-Fi）

- 設定 MQTT broker URL 及 Topic Prefix。

- 點擊「取得遠端監控連結」生成 QR code，掃描後可在任何網路環境透過 Cloud PWA (monitor.html) 即時查看充電狀態並遠端 Start / Stop。

韌體更新

- 「更新至最新韌體」：從 GitHub Releases 自動下載並安裝。

- 「上傳韌體」：手動選擇本地 tes_charger.bin 檔案。

充電紀錄

- 顯示最近 20 次充電紀錄（由新到舊）。

- 欄位：充電時間、電量（Wh，PSU 未接時標註「預估」）、SOC 起→終、停止原因。

- 停止原因：SOC 達標 / 電壓達標（顯示停止時電壓）/ 計時完成 / 手動停止 / 故障 / 緊急停止 / BMS 停止。

CAN 診斷面板（進階）

- 摺疊式面板，顯示全部 6 條 CAN 訊息即時解碼值（RX：0x500 / 0x501 / 0x5F0；TX：0x508 / 0x509 / 0x5F8）。

九、故障排除 (FAQ)

- Q：通電後 OLED 沒亮？

A：請確認主電源接線是否正確，以及 12V 降壓電源是否正常輸出。

- Q：連接車輛後無法開始充電？

A：請確認充電槍是否確實插入，以及車輛電源是否已關閉（鑰匙拔除）。查看 OLED 是否顯示錯誤訊息。

- Q：Web UI 無法訪問？

- AP 模式：確認手機已連接 TES-Charger 熱點，再訪問 http://192.168.4.1 或 http://tes-charger.local。

- STA 模式：確認手機與裝置在同一 Wi-Fi 下，使用 http://tes-charger.local 訪問。

- 若 Wi-Fi 連線失敗導致無法訪問 Web UI：進入 OLED 設定選單 → WiFi Info 確認 IP；或重置 Wi-Fi（刪除 SSID 記錄後重啟，裝置將回到 AP 模式）。

- Q：按下 EMERGENCY 緊急停止後無法恢復？

A：由實體按鈕觸發的緊急停止需手動復歸。進入設定選單 → 選擇「Reset Fault」→ 短按 SETTING 確認。

- Q：推播通知沒有收到？

A：確認 ntfy App 已訂閱正確 Topic，且裝置已連接 Wi-Fi（AP 模式下無法發送）。可在 Web UI 點擊「發送測試通知」驗證設定。

- Q：OTA 更新失敗？

A：確認裝置已連接可上網的 Wi-Fi。若線上更新失敗，可改用「上傳韌體」手動上傳 tes_charger.bin。

感謝您的支持！
開源專案地址：github.com/a950523a/TES-Taiwan-Electric-Scooter-Charging-Controller

技術交流社群：https://www.facebook.com/share/g/15KmiEWLdY/

附錄 A：故障碼 (Fault Flags) 解析表

當充電控制器因異常而停止，並在 OLED 螢幕上顯示 Fault Flags: 0xXX 時，您可以透過以下表格，解析該十六進位碼所代表的具體意義。

數據來源： 本控制器顯示的故障碼，是直接來自您車輛 BMS 透過 CAN Bus 訊息 ID 0x500 (Byte 0) 回報的數值。

TES-0D-02-01 標準故障旗標對照表

位元 (Bit) | 十六進位值 (Hex) | 二進位遮罩 (Mask) | 故障描述 (中文) | 故障描述 (English) | 可能原因與建議
Bit 0 | 0x01 | 0b00000001 | 供電系統異常 | Supply System Error | 車輛 BMS 認為充電樁提供的電壓/電流不穩定或與其預期不符。請檢查您的電源供應器是否穩定，或嘗試降低充電電流。
Bit 1 | 0x02 | 0b00000010 | 電池過電壓 | Battery Over-Voltage | 電池組總電壓或某個電芯的電壓超過了安全上限。BMS 已強制停止充電以保護電池。
Bit 2 | 0x04 | 0b00000100 | 電池電壓不足 | Battery Under-Voltage | 電池組電壓過低，可能處於深度放電狀態，BMS 拒絕充電。
Bit 3 | 0x08 | 0b00001000 | 電池電流差異 | Battery Current Difference | BMS 內部測量到的電流與其預期值存在較大差異。
Bit 4 | 0x10 | 0b00010000 | 電池高溫 | Battery High Temperature | 電池溫度超過了安全上限。BMS 已強制停止充電以保護電池。請讓車輛靜置降溫後再嘗試。
Bit 5 | 0x20 | 0b00100000 | 電池電壓差異 | Battery Voltage Difference | 電池組內部各電芯之間的電壓差過大（電芯不平衡）。BMS 已停止充電以防止部分電芯過充。

特殊情況：Fault Flags: 0x00

如果您在 OLED 故障頁面看到 Fault Flags: 0x00，這表示車輛 BMS 並沒有回報任何具體的故障旗標。

在這種情況下，充電停止的最可能原因是：

- 電流差異異常 (由車輛觸發)：車輛 BMS 請求的充電電流，與您設定的「Max Current」存在巨大差異（通常是 BMS 請求降流，但您的電源仍在以最大電流輸出）。本控制器會持續回報「Max Current」，BMS 在比較後會主動停止充電。這是一個重要的安全保護機制。
- CP 信號丟失：充電過程中，CP 信號線的連接可能出現瞬時中斷。
- 其他未定義的系統級問題。

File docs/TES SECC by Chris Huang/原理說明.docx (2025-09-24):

TES 直流充電控制器 - 工作原理說明

前言
本控制器旨在為 TES-0D-02-01 標準的電動機車，提供一個高度可配置、高功率的直流充電解決方案。它的核心是模擬一個標準充電樁的行為，與您車輛的電池管理系統 (BMS) 進行「交握」，以實現充電。為了幫助您更好地理解和使用本套件，以下將簡述其工作原理及現階段的功能限制。

一、 TES 充電的「對話」基礎：CP 與 CAN
電動機車的充電過程，依賴於車輛與充電樁之間的持續溝通，主要通過兩條線路：

1. CP (Control Pilot) 控制導引線：一條簡單的類比信號線。充電樁透過它來感知「車輛是否插入」，車輛也透過它來告知「我已準備好」。
2. CAN Bus 通訊總線：一條高速的數位通訊線。在充電過程中，車輛的 BMS 會透過它，像發送訊息一樣，持續地告诉充电桩：「我現在需要多少安培 (A) 的電流」。

二、 本控制器是如何「扮演」充電樁的？
本控制器，其核心任務就是精確地扮演「充電樁」的角色，與您的車輛 BMS 進行交握。

1. 啟動交握：當您連接車輛並按下開始充電後，本控制器會提供 12V VP 輔助電源喚醒車輛 BMS，並開始與 BMS 進行 CAN Bus 通訊以及讀取 CP 電壓訊號，完成初始的安全握手流程。
2. 充電時間估算方式：
1. 數據來源：車輛回報的**「最大充電時間」**。這個時間是 BMS 根據當前電池狀態（電壓、溫度、SOC 等）動態估算出的總充電時長。
2. 計算方式：

控制器內部有一個精確的計時器，從充電開始時（直流接觸器閉合）計時，記錄**「已充電時間」**。

剩餘時間的計算公式為：剩餘時間 = BMS 提供的最大充電時間 - 控制器記錄的已充電時間。

3. 電流控制的實現方式（重要！請理解其限制）：
  - 「我是如何控制車輛充電電流的？」
    - 在充電開始前，本控制器會透過 CAN Bus，向車輛 BMS 宣告一個**「最大可供應電流」。這個值，就是您在控制器設定中（或 Web UI 上）設定的「Max Current」**。
    - 例如，如果您設定了 30A，控制器就會告訴 BMS：「我最多只能給你 30A」。
    - 車輛 BMS 在收到這個「能力上限」後，它在整個充電過程中，請求的電流就永远不会超过 30A。
  - 「充電樁的電源供應器 (例如『大炮』電源) 需要如何配合？」
    - 您必須手動將您的電源供應器的「電流輸出」，設定為與本控制器「Max Current」完全相同的值！
    - 例如，控制器設定 30A，您的「大炮」電源也必須設定為 30A。
4. 充電過程中的電流回報：
  - 在充電過程中，本控制器的韌體會直接將設定的最大充電電流**直接當作「實際輸出電流」**回報給 BMS。
  - 因此，電源的電流設定必須與車輛的期望值相匹配，以確保通訊的有效性。

三、 現階段的功能與局限性（請務必了解）

- 優勢：
  - 高功率充電：您可以搭配高性能的電源供應器，實現遠超原廠的充電速度。
  - 高度可配置：您可以自由設定最大充電電流和目標 SOC。
  - 智慧化：提供 OLED 顯示、Web 遠端監控、OTA 韌體更新等原廠沒有的功能。
- 局限性：
  - 充電時間準確性依賴於您車輛 BMS 的估算能力。
  - 無法自動調整電流：本控制器無法在充電過程中，動態地、自動地調整您外接電源供應器的電流輸出。
  - 使用場景：如果車輛 BMS 在充電中途，請求的電流低於您設定的上限（例如，從 30A 降到 15A），而您的電源仍然持續輸出 30A，充電會在幾秒內因「電流差異異常」而停止。
  - 操作流程：當需要降低充電電流時（例如從 30A 降至 15A），您必須：
    1. 手動停止充電。
    2. 在您的電源供應器上，將電流上限改為 15A。
    3. 在本控制器上，將「Max Current」也改為 15A。
    4. 重新開始充電。
  - 結論：本產品在現階段，是一個功能強大的**「手動擋」**高性能充電器。它提供了高功率充電的能力，但需要使用者對充電過程有更多的了解和手動介入。

四、 附錄：TES-0D-02-01 交握時序與數據詳解 (技術細節)

本節內容旨在為高階用戶和開發者，提供更深入的技術細節，解釋本控制器是如何精確模擬充電樁行為的。

1. 交握時序 (Simplified Sequence)

步驟 | 觸發動作 | 物理信號 (CP) | CAN Bus 通訊 (車 -> 樁) | CAN Bus 通訊 (樁 -> 車) | 控制器動作
1 | 按下開始充電 | 電壓變化 | - | - | 啟動 VP (12V)
2 | BMS 喚醒 | 維持電壓 | #500, #501 發送 (請求參數) | - | 接收車輛參數
3 | 參數確認 | 維持電壓 | #500, #501 持續發送 | #508, #509 發送 (樁能力) | 比較參數，發送自身能力
4 | BMS 許可 | 電壓再次變化 | #500 中「允許充電」旗標設為 1 | #508, #509 持續發送 | 檢測到雙重許可
5 | 開始充電 | 維持電壓 | #500 持續發送 (動態電流指令) | #509 持續發送 (回報電壓/電流) | 閉合直流接觸器，開始供電
6 | 充電結束 | 電壓恢復 | #500 中「允許充電」旗標設為 0 | #508 中「停止控制」旗標設為 1 | 斷開直流接觸器，停止供電

2. 關鍵 CAN 訊息與本控制器的模擬值

來自車輛的關鍵訊息 (控制器讀取)

- ID: 0x500 (車輛狀態)
  - 充電電流命令 (Byte 2, 3)：BMS 期望的充電電流，單位 0.1A。這是控制器追隨的目標。
  - 充電電壓上限 (Byte 4, 5)：BMS 允許的最高充電電壓，單位 0.1V。
  - 允許充電旗標 (Byte 1, bit 0)：充電的「軟開關」。
  - 充電前停止旗標 (Byte 1, bit 3)：BMS 在充電前停止的信號。
- ID: 0x501 (車輛參數)
  - 當前 SOC (Byte 1)：電池電量百分比。
  - 最大充電時間 (Byte 2, 3)：BMS 估算的總充電時間（分鐘）。

本控制器發送的關鍵訊息 (模擬值設定)

- ID: 0x508 (充電樁狀態)
  - 可輸出電壓 (Byte 2, 3)：控制器會回報您在設定中儲存的最大電壓值，單位 0.1V。
  - 可輸出電流 (Byte 4, 5)：控制器會回報您在設定中儲存的「Max Current」，單位 0.1A。這是告訴 BMS「我的能力上限」的關鍵參數。
  - 充電樁停止控制旗標 (Byte 1, bit 0)：當充電結束或出錯時，控制器會將此旗標設為 1，通知 BMS。
- ID: 0x509 (充電樁參數)
  - 實際輸出電壓 (Byte 2, 3)：控制器會讀取 ADC 的電壓測量值。
  - 實際輸出電流 (Byte 4, 5)：控制器不會實際測量電流，而是將最大充電流，直接作為「實際輸出電流」回報給 BMS。這就是為什麼您的電源供應器設定必須與 BMS 的請求相匹配的原因。

透過對以上時序和數據的精確模擬，本控制器得以在 TES-0D-02-01 標準框架下，實現與各種車輛的兼容充電。

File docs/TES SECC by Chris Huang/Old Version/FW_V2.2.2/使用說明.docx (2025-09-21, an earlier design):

TES 直流充電控制器 (智慧高功率版) V1 - 使用說明書

型號：TES SECC by Chris Huang V1.1
韌體版本：v2.2.2 | 檔案系統版本：v1.1.0

【極重要】安全警告與免責聲明

在開箱、安裝或使用本產品前，請您務必仔細閱讀並完全理解以下所有條款。您的任何使用行為，即構成您對本協議所有條款的完全接受與同意，並自願承擔所有相關風險與責任。

- 高壓危險：本產品涉及高壓直流電，不正確的安裝或操作可能導致觸電、火災或設備損壞。使用者必須具備合格的電子電工知識。
- 非安規認證：本產品為開源專案產品，未經 BSMI 等強制性安規認證，僅供個人實驗與研究使用，嚴禁作為商業成品轉售或在公共場合提供充電服務。
- 責任豁免：在法律允許的最大範圍內，對於因使用本產品而導致的任何直接或間接損害，作者 Chris Huang (a950523a) 不承擔任何形式的法律責任。
- 使用者必須具備 TES 通訊協議之專業知識：本產品透過深度解析 TES-0D-02-01 通訊協議以實現充電控制。使用者必須充分理解其交握流程、安全機制及潛在風險。不正確的設定或使用，可能導致車輛或充電設備損壞。
- 詳細內容請參閱隨附的 免責聲明 及 原理說明 檔案，請閱讀完畢再使用本套件。
- 本套件為開源專案，操作模式及功能可能會隨著韌體更新而不同，請在每次韌體更新前自行上Github專案的Release中查看更新說明

一、 套件開箱與內容物檢查

感謝您選擇我的套件！開箱後，請確認您收到了以下所有物品：

- TES 直流充電控制器主機 x 1

二、 產品接口與功能說明


2-1

2-2

2-3

3-1

4-2

GD/VP

4-2

D-/D+/GND/CP

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
1. OLED 顯示螢幕：顯示實時充電狀態、設定選單等資訊。
2. 狀態指示燈 (LED)：
  1. 橘燈：待機 / 電源指示。
  2. 綠燈：充電中 (閃爍) / 充電完成 (常亮)。
  3. 紅燈：故障 / 異常 (常亮)。
3. 操作按鈕：
  1. START / UP (上)：開始充電 / 在選單中向上移動。
  2. STOP / DOWN (下)：停止充電 / 在選單中向下移動。
  3. SETTING (設定)：在主畫面時短按循環目標 SOC / 長按進入設定選單 / 在設定選單中短按確認、長按返回。
  4. EMERGENCY：緊急停止
4. 接口：
  1. DC 120V IN：主電源輸入接口。
  2. 充電槍控制訊號：連接至充電槍的控制線束接口(和iE/勁炫 原廠大充一樣，但還是推薦檢查一下) (VP, GD, CP, CANH(D+), CANL(D-))。
  3. 12V電磁閥控制輸出：用於控制充電槍上的鎖定電磁閥
  4. 12V直流接觸器控制輸出：用於控制外部直流接觸器的訊號輸出。
  5. USB-C (位於側邊)：用於首次韌體燒錄或緊急除錯，日常使用無需連接。

三、 首次安裝與設定

步驟 1：硬體接線 (請在完全斷電的情況下進行！)

1. 將您的直流電源供應器的電源輸出，連接到本機的 DC 120V IN 接口。
2. 將本機的 直流接觸器控制 輸出，連接到您的直流接觸器的線圈控制端(低功率可不安裝(iE/勁炫))。
3. 將您的充電槍控制線束，正確地連接到本機的 充電槍控制訊號 接口。
4. 仔細檢查所有接線是否正確、牢固，特別是正負極性。

步驟 2：首次通電與 Wi-Fi 設定 (AP 模式)

1. 首次通電時，設備會進入 AP (熱點) 模式。
2. 在您的手機或電腦上，尋找一個名為 TES_Charger_ESP32 的 Wi-Fi 熱點，並連接它。密碼為 12345678。
3. 連接成功後，請手動打開瀏覽器，訪問 192.168.4.1。
4. 您會看到充電樁的 Web UI 主頁面。找到「Network Settings」區塊。
5. 在「Setup New WiFi」表單中，輸入您家中 Wi-Fi 的名稱 (SSID) 和密碼。*非必要，AP模式即有完整功能
6. 點擊「Save & Reboot」。設備將會儲存設定並自動重啟。

步驟 3：連接到您的家庭網路 (STA 模式)

1. 設備重啟後，會自動嘗試連接到您剛剛設定的 Wi-Fi。
2. 請將您的手機或電腦也連回您家的 Wi-Fi。
3. 在 OLED 螢幕上的設定->Network或您的路由器管理頁面中，找到充電控制器的新 IP 位址 (例如 192.168.xx.xx)。
4. 在瀏覽器中訪問這個新的 IP 位址，您就可以在家庭網路中監控和控制充電樁了。

四、 日常操作

1. 透過 OLED 和按鈕操作

- 充電：連接車輛後，按下 START 按鈕。
- 停止：充電中，按下 STOP 按鈕。
- 設定：在待機狀態下，長按 SETTING 進入選單。使用 UP/DOWN 選擇，短按 SETTING 進入/確認，長按 SETTING 返回上一級。

2. 透過 Web UI 遠端操作

- 在瀏覽器中訪問設備的 IP 位址。
- Live Data：查看實時充電數據。
- Controls：點擊 START / STOP 按鈕(僅在OLED設定頁面未開啟時可操作)，或點擊 Settings 彈出設定視窗。
- Firmware Update：檢查並執行線上韌體更新 (OTA)。
- Network Settings：重新設定 Wi-Fi 或重置網路。

五、 韌體更新 (OTA)

我們建議您定期檢查並更新韌體，以獲得最新的功能和 Bug 修正。

1. 確保您的充電樁已連接到可上網的 Wi-Fi。
2. 在 OLED 的About選單或 Web UI 的「About & Update」頁面，點擊「Check for Updates」。
3. 若顯示JSON parse error請再按下檢查更新一次
4. 如果檢測到新版本，按鈕會變為Start Update
5. 點擊「開始更新」，設備將自動下載並安裝韌體和網頁檔案，此過程可能需要幾分鐘並自動重啟數次，請耐心等待。更新過程中請勿斷電！

*目前韌體沒有到很完整，若韌體和檔案系統皆須更新需手動操作兩次

六、 故障排除 (FAQ)

- Q: 通電後 OLED 沒亮？
  - A: 請檢查您的 120V 電源是否正常供電。
- Q: 連接車輛後無法開始充電？
  - A: 請檢查充電槍是否插好，並查看 OLED 螢幕是否有任何錯誤訊息。
- Q: Web UI 無法訪問？
  - A: 請確認您的手機/電腦與充電樁是否連接在同一個 Wi-Fi 網路下，並確認 IP 位址是否正確。

感謝您的支持！
開源專案地址：github.com/a950523a/TES-Taiwan-Electric-Scooter-Charging-Controller

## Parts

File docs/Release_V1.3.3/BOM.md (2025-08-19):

## 物料清單 (Bill of Materials - BOM)

這份清單主要基於我當前的原型製作經驗，並以淘寶等電商平台為主要採購來源。
**提供的連結僅為我當時購買或找到的參考，不保證其品質或長期有效。建議您根據「淘寶搜索關鍵字」尋找信譽良好的商家購買。**

### 核心控制器與模組

| 數量 (Qty) | 元件名稱 (Part Name) | 淘寶搜索關鍵字 | 參考連結 (Reference Link) |
| :--- | :--- | :--- | :--- |
| 1 | ESP32 開發板 | `ESP32開發版` | [點擊這裡](https://e.tb.cn/h.hiRBgOphii6aqCW?tk=dw2z4YwBA1k) |
| | *(註：可選擇ESP32-S3，未來專案越來越複雜一般的ESP32可能因性能不足而無法執行，只是ESP32-S3引腳定義會有些許不同，請自行修改)* | | |
| 1 | CAN Bus 模組 | `MCP2515模塊` | [點擊這裡](https://e.tb.cn/h.hiQmzbQqu1oH8JV?tk=z7kX4YDbctz) |
| 1 | **主降壓電源 (12V)** | `耐高壓12V降壓模塊` | [點擊這裡](https://e.tb.cn/h.hikC8w5RuqK0mvh?tk=xkQA4YDcYHa) |
| | *(註：此模組用於從主電源降壓至12V，**建議耐壓120V**。您也可以使用獨立的12V電源供電。供電能力3A以上。)* | | |
| 1 | **降壓電源 (5V)** | `5V降壓模塊` | [點擊這裡](https://e.tb.cn/h.hjf1qiHCpCsEg6O?tk=AByS4XKlhL9) |
| | *(註：也可使用隔離型降壓模塊，可以讓電路運作更穩定)* | | |
| 1 | 5V繼電器 | `5V繼電器模塊` | [點擊這裡](https://e.tb.cn/h.hiQtbJft1vH2RAP?tk=Pgtz4YDUVTH) |
| 1 | ADS1115 | `ADS1115模塊` | [點擊這裡](https://e.tb.cn/h.hj46n5YqDCprkm7?tk=1IKN4XKpAXf) |
| 1 | OLED 顯示屏 | `0.96寸 OLED IIC` `SSD1306` | [點擊這裡](https://e.tb.cn/h.hiQxBdKZhg7zoPj?tk=GMqx4YDidKZ) |

### 被動元件

*(註：此類元件用量少，若不想一次購買大量元件，可以到本地的電子材料行購買。)*

| 數量 (Qty) | 數值 (Value) / 類型 | 淘寶搜索關鍵字 |
| :--- | :--- | :--- |
| 1 | 0.1uF (標示104) / 陶瓷電容| `0.1uF瓷片電容` |
| 2 | 1uF (標示105) / 陶瓷電容| `1uF瓷片電容` |
| | *(註：用於ADS1115分壓電阻濾波。)* | |
| 1 | 10uF, 16V / 10uF電解電容  |  |
| | *(註：與0.1uF陶瓷電容配合，用於5V電源濾波。)* | |
| 4 | 150Ω / 1/2W電阻 | `150歐姆 1/2W電阻` |
| 1 | 51Ω / 1/2W電阻 | `150歐姆 1/2W電阻` |
| | *(註：以上兩個為CP分壓電阻，功率稍大更穩定。其餘三個150Ω為LED限流電阻)* | |
| 1 | 348kΩ / 0.1%高精密電阻 | `348K歐姆 0.1%電阻` |
| 1 | 12kΩ / 0.1%高精密電阻 | `12K歐姆 0.1%電阻` |
| | *(註：以上兩個為120V分壓電阻，誤差過大會造成主電源電壓量測不準確，可能須手動校準)* | |

### 連接器、按鈕與其他 

*(註：部分元件用量少，若不想一次購買大量元件，可以到本地的電子材料行購買。)*

| 數量 (Qty) | 元件名稱 (Part Name) | 類型/規格 (Type/Spec) | 備註 |
| :--- | :--- | :--- | :--- |
| 4 | 按鈕 | 6x6x5mm, 2腳或4腳直插 | |
| 3 | LED 指示燈 | 3mm 或 5mm, 紅/綠/橘 |
| 1 | 洞洞板/萬用板 | 12x18cm |*若零件塞的夠緊湊可以選用更小片的|
| 若干 | 排針/排母 | 2.54mm 間距 | 用於將模組固定在萬用板上，建議使用排母來連接元器件，保有修改的彈性。|
| 若干 | 杜邦線 | 公對母 / 母對母 | 僅用於臨時測試，**雜訊干擾有可能使硬體無法正常運作**。 |
| 若干 | 電子線 | AWG 22-26 | 用於焊接洞洞板上的信號線。 |
| 若干 | **電子線** | **AWG 16-18** | **用於12V電源輸出等電流較大的部分。** |

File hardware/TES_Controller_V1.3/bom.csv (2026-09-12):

designator | part | value | device | supplier
BOOT | TS-1088-AR02016 |  | ts-1088-ar02016 | C720477
C1 | CL31A226KAHNNNE | 22uF | cl31a226kahnnne | C12891
C2 | CL10A105KB8NNNC | 1uF | cl10a105kb8nnnc | C15849
C3 | CC0603KRX7R9BB104 | 100nF | cc0603krx7r9bb104 | C14663
C4 | CC0603KRX7R9BB104 | 100nF | cc0603krx7r9bb104 | C14663
C7 | CL10A105KB8NNNC | 1uF | cl10a105kb8nnnc | C15849
C8 | CL10A105KB8NNNC | 1uF | cl10a105kb8nnnc | C15849
C9 | CL31A106KBHNNNE | 10uF | cl31a106kbhnnne | C13585
C10 | CL31A226KAHNNNE | 22uF | cl31a226kahnnne | C12891
C11 | CC0603KRX7R9BB104 | 100nF | cc0603krx7r9bb104 | C14663
C12 | CC0603KRX7R9BB104 | 100nF | cc0603krx7r9bb104 | C14663
C13 | CC0603KRX7R9BB104 | 100nF | cc0603krx7r9bb104 | C14663
C14 | CC0603KRX7R9BB104 | 100nF | cc0603krx7r9bb104 | C14663
C15 | CC0603KRX7R9BB104 | 100nF | cc0603krx7r9bb104 | C14663
C16 | CL31A226KAHNNNE | 22uF | cl31a226kahnnne | C12891
C17 | CL31A106KBHNNNE | 10uF | cl31a106kbhnnne | C13585
C20 | CC0603KRX7R9BB104 | 100nF | cc0603krx7r9bb104 | C14663
C28 | CC0603KRX7R9BB104 | 100nF | cc0603krx7r9bb104 | C14663
C29 | CC0603KRX7R9BB104 | 100nF | cc0603krx7r9bb104 | C14663
CN1 | B2PS-VH(LF)(SN) |  | b2ps-vh(lf)(sn) | C158007
CN2 | S4B-XH-A(LF)(SN) |  | s4b-xh-a(lf)(sn) | C157925
CN3 | DG381-3.5-02P-14-00A(H) |  | dg381-3.5-02p-14-00a(h) | C5272864
CN5 | DG381-3.5-02P-14-00A(H) |  | dg381-3.5-02p-14-00a(h) | C5272864
CN6 | DG381-3.5-02P-14-00A(H) |  | dg381-3.5-02p-14-00a(h) | C5272864
D1 | SS14 |  | ss14_c2480 | C2480
D3 | SMBJ12A |  | smbj12a_c908793 | C908793
D4 | SS14 |  | ss14_c2480 | C2480
D5 | USBLC6-2SC6 |  | usblc6-2sc6_c7519 | C7519
EMERGENCY | TS-1187A-B-A-B |  | ts-1187a-b-a-b | C318884
EN | TS-1088-AR02016 |  | ts-1088-ar02016 | C720477
G |  |  | led_th-r_5mm
H1 |  |  | hdr-f_2.54_1x4p
H2 |  |  | hdr-f_2.54_1x3p
Q1 | AO3400A |  | ao3400a_c20917 | C20917
Q2 | AO3400A |  | ao3400a_c20917 | C20917
Q3 | AO3400A |  | ao3400a_c20917 | C20917
Q4 | AO3401A |  | ao3401a_c15127 | C15127
R |  |  | led_th-r_5mm
R1 | 0603WAF1002T5E | 10kΩ | 0603waf1002t5e | C25804
R2 | 0402WGF5101TCE | 5.1kΩ | 0402wgf5101tce | C25905
R3 | 0402WGF5101TCE | 5.1kΩ | 0402wgf5101tce | C25905
R5 | 0603WAF1002T5E | 10kΩ | 0603waf1002t5e | C25804
R6 | 0603WAF1002T5E | 10kΩ | 0603waf1002t5e | C25804
R8 | FRP1206F51R0TS | 51Ω | frp1206f51r0ts | C7468320
R9 | FRC1210F1500TS | 150Ω | frc1210f1500ts | C2933805
R10 | RT0603BRD07348KL | 348kΩ | rt0603brd07348kl | C861336
R11 | RT0603BRD0712KL | 12kΩ | rt0603brd0712kl | C326735
R12 | RC0603FR-07430RL | 430Ω | rc0603fr-07430rl | C137721
R13 | 0603WAF4700T5E | 470Ω | 0603waf4700t5e | C23179
R14 | 0603WAF5100T5E | 510Ω | 0603waf5100t5e | C23193
R16 | 0603WAF1000T5E | 100Ω | 0603waf1000t5e | C22775
R17 | 0603WAF1002T5E | 10kΩ | 0603waf1002t5e | C25804
R19 | 0603WAF1000T5E | 100Ω | 0603waf1000t5e | C22775
R20 | 0603WAF1002T5E | 10kΩ | 0603waf1002t5e | C25804
R21 | 0603WAF1200T5E | 120Ω | 0603waf1200t5e | C22787
R26 | 0603WAF1002T5E | 10kΩ | 0603waf1002t5e | C25804
R28 | 0603WAF1002T5E | 10kΩ | 0603waf1002t5e | C25804
R29 | 0603WAF1000T5E | 100Ω | 0603waf1000t5e | C22775
R30 | 0603WAF220JT5E | 22Ω | 0603waf220jt5e | C23345
R31 | 0603WAF220JT5E | 22Ω | 0603waf220jt5e | C23345
R32 | 0603WAF1002T5E | 10kΩ | 0603waf1002t5e | C25804
SB1 | 0603WAF0000T5E | Jumper | jumper solder bridge copy copy | C21189
SETTING | TS-1187A-B-A-B |  | ts-1187a-b-a-b | C318884
START | TS-1187A-B-A-B |  | ts-1187a-b-a-b | C318884
STOP | TS-1187A-B-A-B |  | ts-1187a-b-a-b | C318884
U1 | ESP32-S3-WROOM-1-N16R8 |  | esp32-s3-wroom-1-n16r8 | C2913202
U5 | ADS1115IDGSR |  | ads1115idgsr | C37593
U6 | AMS1117-3.3 |  | ams1117-3.3_c6186 | C6186
U8 | LMZM23601V5SILR |  | lmzm23601v5silr | C2868357
U10 | DG301-5.0-02P-14-00A(H) |  | dg301-5.0-02p-14-00a(h) | C5128812
U12 | TJA1051T/3/1J |  | tja1051t/3/1j | C38695
USB1 | TYPE-C16PIN |  | type-c16pin | C393939
W1 | SOLDERPAD-1P |  | solder wire pad
W2 | SOLDERPAD-1P |  | solder wire pad
W3 | SOLDERPAD-1P |  | solder wire pad
W4 | SOLDERPAD-1P |  | solder wire pad
Y |  |  | led_th-r_5mm

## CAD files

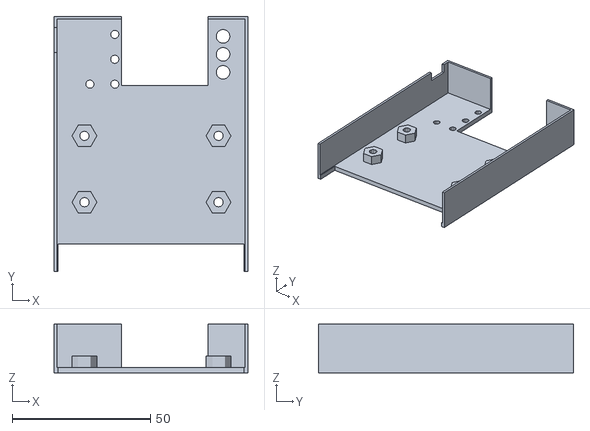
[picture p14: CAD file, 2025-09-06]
docs/PCB/TES_Controller_V1_Case_Top.stl
70.2 x 92.3 x 17.6

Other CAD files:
docs/PCB/OldVersions/TES_Controller_V1_Case_Top.0001.ipt
docs/PCB/TES_Controller_V1_Case_Base.ipt
docs/PCB/TES_Controller_V1_Case_Button.ipt
docs/PCB/TES_Controller_V1_Case_Top.ipt

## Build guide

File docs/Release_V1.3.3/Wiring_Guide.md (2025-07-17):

# 接線指南 (Wiring Guide)

**警告：在進行任何焊接或連接之前，請確保所有設備都已斷電！** 
建議使用萬用板或PCB進行最終的電路搭建，以保證連接的可靠性和安全性。

本指南基於程式碼中的預設引腳定義。如果您修改了引腳，請對應更改接線。

部分引腳定義可能需依您的ESP32型號或程式碼設定進行調整。以下以"*"標示

---

### 1. 電源分區與接地策略

本專案採用「二次隔離」電源架構，將系統分為「啟動電源部分」和「控制部分」。

*   **12V 啟動電源**：由主電源降壓而來，用於供應車端VP啟動充電及二次降壓給控制電路使用。
*   **5V 控制電源**：由 12V 經過 5V DC-DC轉換而來，專門為ESP32、CAN模組、OLED等核心控制電路供電。 
*   **公共地 (GND)**：所有模組的GND最終需連接在一起，形成共同參考電位。建議採用星形接地以獲最佳效果。

---

### 2. 模組連接詳解

#### 主控制器 (ESP32)
*   **電源**:
    *   `VIN`: 隔離型DC-DC模組的 **+5V** 輸出。
    *   `GND`: **公共地 (GND)**。

#### CAN Bus 模組 (MCP2515)
*   **電源**:
    *   `VCC`: **+5V**。
    *   `GND`: **公共地 (GND)**。
*   **SPI 通訊**:
    *   `CS`: **GPIO 5**。*
    *   `SO` (MISO): **GPIO 19**。
    *   `SI` (MOSI): **GPIO 23**。
    *   `SCK`: **GPIO 18**。
*   **中斷信號**:
    *   `INT`: **GPIO 35**。*
*   **CAN接口**:
    *   `CAN-H`：**充電槍CAN-H**。
    *   `CAN-L`：**充電槍CAN-L**。
    *   **連接至車輛時須確保沒有短路及功能正常，否則無法正常運作甚至燒BMS!!!**

#### ADS1115
*   **電源**:
    *   `VDD`：**+5V**。
    *   `GND`: **公共地 (GND)**。
*   **IIC**:
    *   `SCL`：**GPIO 22**。
    *   `SDA`：**GPIO 21**。
*   **地址設定**:
    *   `ADDR`: **公共地 (GND)**，將I2C地址設為 `0x48`。
*   **差分測量A0-A1(主電源)**:
    1.  **分壓電路**:
        *   將 **348kΩ** 電阻 (R1) 和 **12kΩ** 電阻 (R2) **串聯**。
        *   串聯電路的頂端連接到主電源的 **正極 (+)**。
        *   串聯電路的底端連接到**公共地 (GND)**。

    2.  **差分信號連接**:
        *   將 **R1和R2的連接點** (即分壓點) 連接到 ADS1115 的 `A0` 引腳。
        *   將 **R2的底端** 連接到 ADS1115 的 `A1` 引腳。

    3.  **濾波電路**:
        *   在 `A0` 和 `A1` 之間，並聯一個 **1uF 的陶瓷電容**。
*   **差分測量A2-A3(CP)**:
    1.  **分壓電路**:
        *   將 **150kΩ** 電阻 (R1) 和 **51Ω** 電阻 (R2) **串聯**。
        *   串聯電路的頂端連接到 **CP**。
        *   串聯電路的底端連接到 **公共地 (GND)**。

    2.  **差分信號連接**:
        *   將 **R1和R2的連接點** (即分壓點) 連接到 ADS1115 的 `A2` 引腳。
        *   將 **R2的底端** 連接到 ADS1115 的 `A3` 引腳。

    3.  **濾波電路**:
        *   在 `A2` 和 `A3` 之間，並聯一個 **1uF 的陶瓷電容**。
---

### 3. 使用者介面與外設

#### 按鈕與顯示
*   **通用接法**: 所有按鈕的一端都連接到**公共地 (GND)**。
*   **所有LED的負極**（短腳）都通過一個限流電阻（150Ω）連接到**公共地 (GND)**。
*   **按鈕連接**:
    *   Start Button: **GPIO 32**。*
    *   Stop Button: **GPIO 33**。*
    *   Emergency Button: **GPIO 25**。*
    *   Setting Button: **GPIO 4**。*
*   **LED 連接**:
    *   橘色待機LED (正極): **GPIO 14**。*
    *   綠色充電LED (正極): **GPIO 12**。*
    *   紅色錯誤LED (正極): **GPIO 13**。*
*   **OLED 連接**：
    *   `VCC`：**+5V**。
    *   `GND`：**公共地 (GND)**。
    *   `SCL`：**GPIO 22**。
    *   `SDA`：**GPIO 21**。

#### 繼電器與其他
*   **VP 繼電器**:
    *   `+`：**+5V**。
    *   `-`：**公共地 (GND)**。
    *   `S`：**GPIO 15**。*
    *   `COM`：**+12V**。
    *   `NO`：**充電槍VP**。
*   **充電槍剩餘接腳**：
    *    `GD`：**公共地 (GND)**。
    *    `DC+`：**主電源+**。
    *    `DC-`：**主電源-**。
*   **12V降壓電源**：
    *    `Vin+`：**主電源+**。
    *    `Vin-`：**主電源-**。
    *    `12V+`：VP繼電器 的 **COM**。
    *    `12V-`：**公共地 (GND)**。
*   **5V降壓電源**
    *    `Vin+`：**12V+** 或 VP繼電器 的 **COM**。
    *    `Vin-`：**12V-** 或 **公共地 (GND)**。
    *    `5V+`：ESP32 的 **VIN**。
    *    `5V-`：**公共地 (GND)**。

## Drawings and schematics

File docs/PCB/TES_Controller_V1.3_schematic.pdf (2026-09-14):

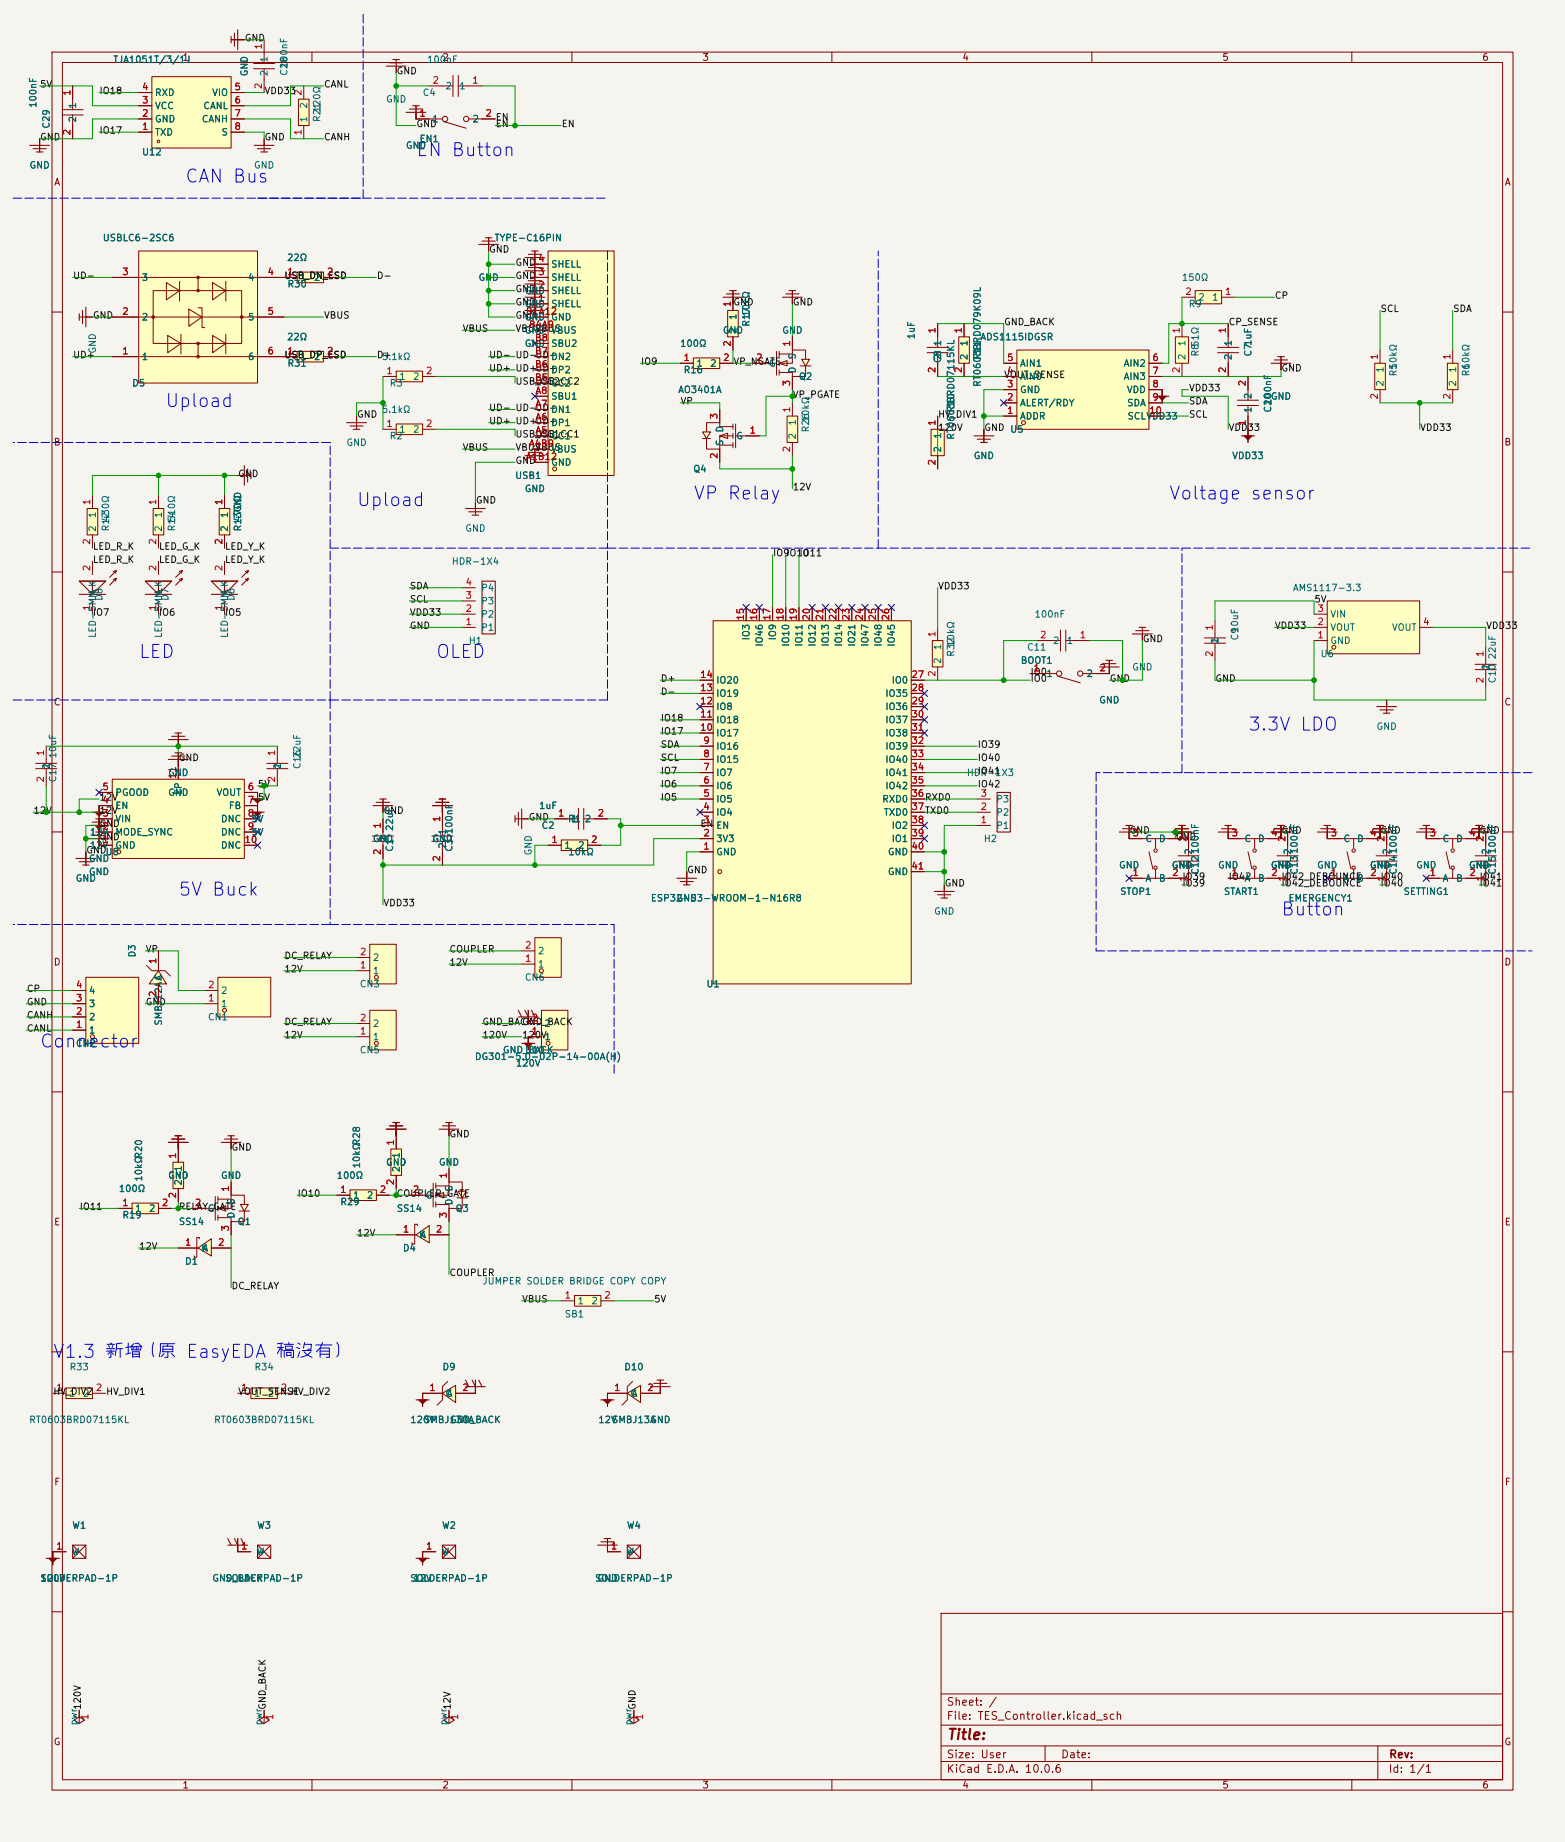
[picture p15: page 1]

VBUS GND UD+ UD+

JUMPER SOLDER BRIDGE COPY COPY C

Size: User | Rev:
KiCad E.D.A. 10.0.6 | Id: 1/1

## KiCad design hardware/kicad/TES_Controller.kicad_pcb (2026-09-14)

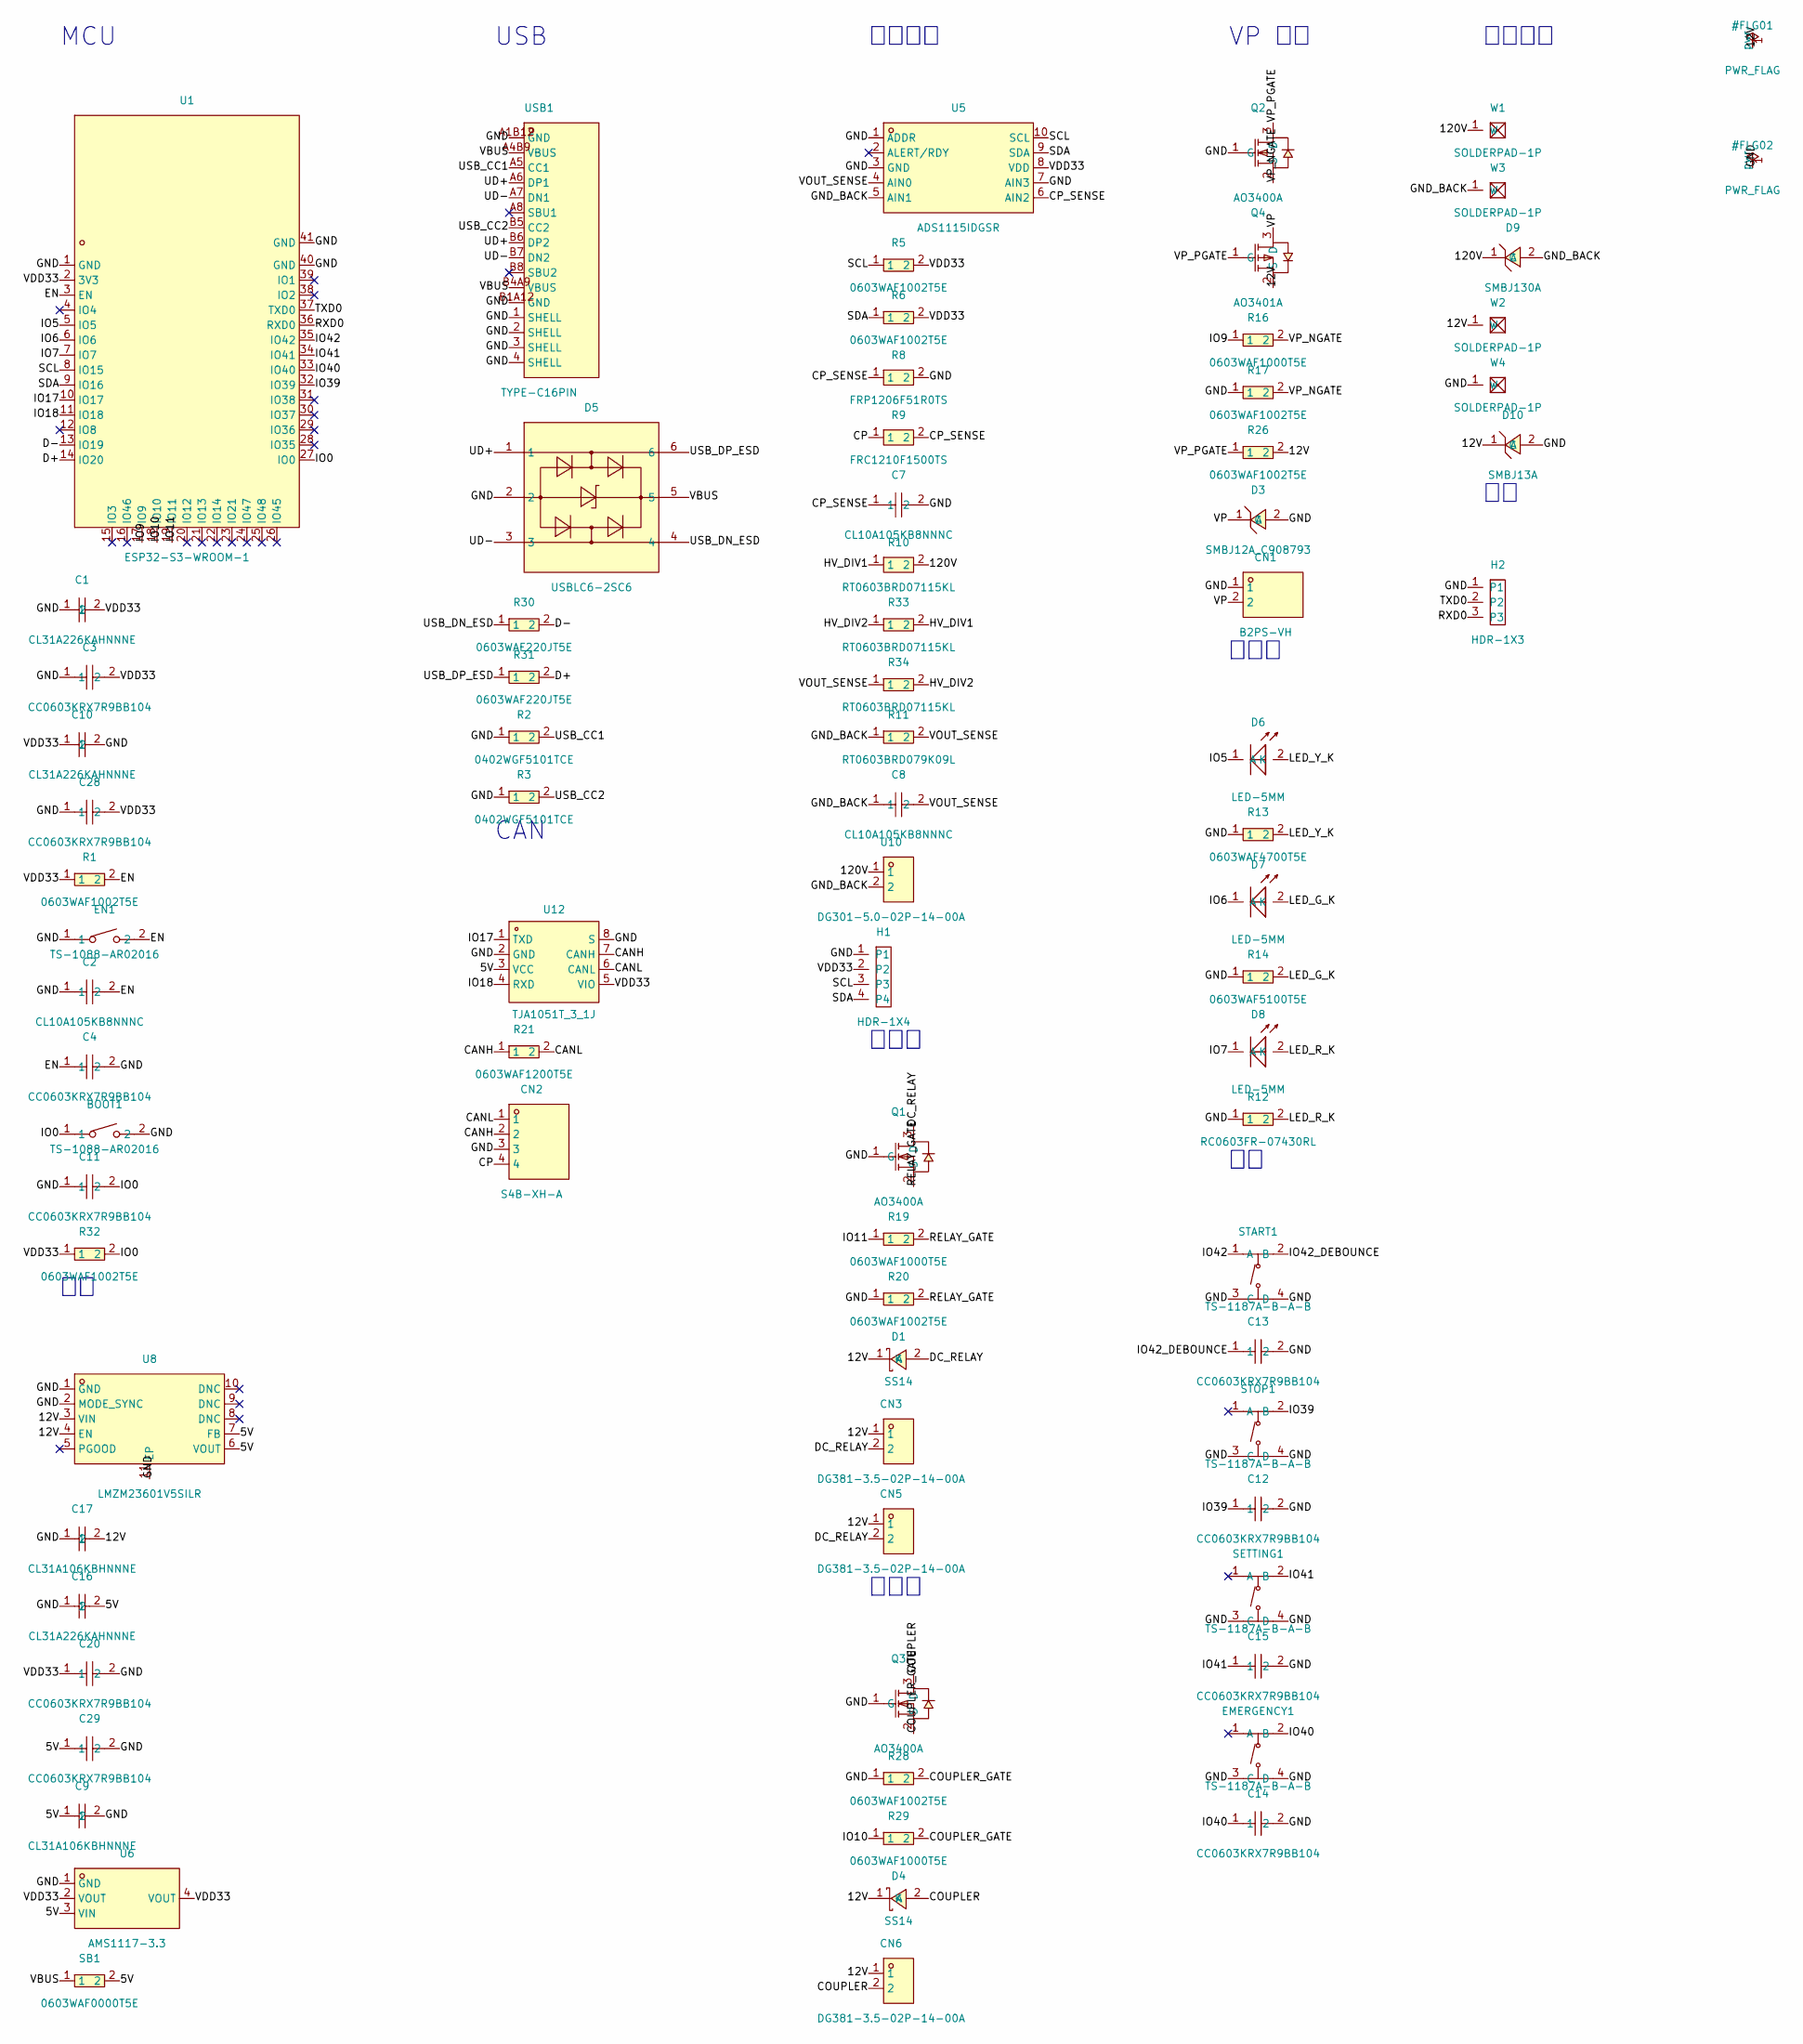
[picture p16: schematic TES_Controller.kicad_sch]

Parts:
BOOT1: TS-1088-AR02016; SW-SMD_L3.9-W3.0-P4.45; MPN TS-1088-AR02016; LCSC Part C720477
C1, C10, C16: CL31A226KAHNNNE; C1206; MPN CL31A226KAHNNNE; LCSC Part C12891
C2, C7, C8: CL10A105KB8NNNC; C0603; MPN CL10A105KB8NNNC; LCSC Part C15849
C3, C4, C11, C12, C13, C14, C15, C20, C28, C29: CC0603KRX7R9BB104; C0603; MPN CC0603KRX7R9BB104; LCSC Part C14663
C9, C17: CL31A106KBHNNNE; C1206; MPN CL31A106KBHNNNE; LCSC Part C13585
CN1: B2PS-VH; CONN-TH_B2PS-VH-LF-SN; MPN B2PS-VH(LF)(SN); LCSC Part C158007
CN2: S4B-XH-A; CONN-TH_S4B-XH-A-LF-SN; MPN S4B-XH-A(LF)(SN); LCSC Part C157925
CN3, CN5, CN6: DG381-3.5-02P-14-00A; CONN-TH_2P-P3.50_DG381-3.5-02P-14-00A; MPN DG381-3.5-02P-14-00A(H); LCSC Part C5272864
D1, D4: SS14; SMA_L4.2-W2.6-LS5.0-RD_1; MPN SS14; LCSC Part C2480
D3: SMBJ12A_C908793; SMB_L4.6-W3.6-LS5.3-RD; MPN SMBJ12A; LCSC Part C908793
D5: USBLC6-2SC6; SOT-23-6_L2.9-W1.6-P0.95-LS2.8-BL; MPN USBLC6-2SC6; LCSC Part C7519
D6, D7, D8: LED-5MM; LED-TH_BD5.8-P2.54-FD
D9: SMBJ130A; SMB_L4.6-W3.6-LS5.3-RD; MPN SMBJ12A; LCSC Part C908793
D10: SMBJ13A; SMB_L4.6-W3.6-LS5.3-RD; MPN SMBJ12A; LCSC Part C908793
EMERGENCY1: TS-1187A-B-A-B; SW-SMD_4P-L5.1-W5.1-P3.70-LS6.5-TL_H1.5; MPN TS-1187A-B-A-B; LCSC Part C318884
EN1: TS-1088-AR02016; SW-SMD_L3.9-W3.0-P4.45; MPN TS-1088-AR02016; LCSC Part C720477
H1: HDR-1X4; HDR-TH_4P-P2.54-V-F
H2: HDR-1X3; HDR-TH_3P-P2.54-V-F
Q1, Q2, Q3: AO3400A; SOT-23-3_L2.9-W1.3-P1.90-LS2.4-BR; MPN AO3400A; LCSC Part C20917
Q4: AO3401A; SOT-23_L2.9-W1.3-P1.90-LS2.4-BR; MPN AO3401A; LCSC Part C15127
R1, R5, R6, R17, R20, R26, R28, R32: 0603WAF1002T5E; R0603; MPN 0603WAF1002T5E; LCSC Part C25804
R2, R3: 0402WGF5101TCE; R0402; MPN 0402WGF5101TCE; LCSC Part C25905
R8: FRP1206F51R0TS; R1206; MPN FRP1206F51R0TS; LCSC Part C7468320
R9: FRC1210F1500TS; R1210; MPN FRC1210F1500TS; LCSC Part C2933805
R10: RT0603BRD07115KL; R0603; MPN RT0603BRD07348KL; LCSC Part C861336
R11: RT0603BRD079K09L; R0603; MPN RT0603BRD0712KL; LCSC Part C326735
R12: RC0603FR-07430RL; R0603; MPN RC0603FR-07430RL; LCSC Part C137721
R13: 0603WAF4700T5E; R0603; MPN 0603WAF4700T5E; LCSC Part C23179
R14: 0603WAF5100T5E; R0603; MPN 0603WAF5100T5E; LCSC Part C23193
R16, R19, R29: 0603WAF1000T5E; R0603; MPN 0603WAF1000T5E; LCSC Part C22775
R21: 0603WAF1200T5E; R0603; MPN 0603WAF1200T5E; LCSC Part C22787
R30, R31: 0603WAF220JT5E; R0603; MPN 0603WAF220JT5E; LCSC Part C23345
R33, R34: RT0603BRD07115KL; R0603; MPN 0603WAF1002T5E; LCSC Part C25804
SB1: 0603WAF0000T5E; R0603; MPN 0603WAF0000T5E; LCSC Part C21189
SETTING1: TS-1187A-B-A-B; SW-SMD_4P-L5.1-W5.1-P3.70-LS6.5-TL_H1.5; MPN TS-1187A-B-A-B; LCSC Part C318884
START1: TS-1187A-B-A-B; SW-SMD_4P-L5.1-W5.1-P3.70-LS6.5-TL_H1.5; MPN TS-1187A-B-A-B; LCSC Part C318884
STOP1: TS-1187A-B-A-B; SW-SMD_4P-L5.1-W5.1-P3.70-LS6.5-TL_H1.5; MPN TS-1187A-B-A-B; LCSC Part C318884
U1: ESP32-S3-WROOM-1; WIRELM-SMD_ESP32-S3-WROOM-1; MPN ESP32-S3-WROOM-1-N16R8; LCSC Part C2913202
U5: ADS1115IDGSR; MSOP-10_L3.0-W3.0-P0.50-LS5.0-BL; MPN ADS1115IDGSR; LCSC Part C37593
U6: AMS1117-3.3; SOT-223-3_L6.5-W3.4-P2.30-LS7.0-BR; MPN AMS1117-3.3; LCSC Part C6186
U8: LMZM23601V5SILR; USIP-10_L3.8-W3.0-TL_TI_SIL; MPN LMZM23601V5SILR; LCSC Part C2868357
U10: DG301-5.0-02P-14-00A; CONN-TH_DEGSON_DG301-5.0-02P; MPN DG301-5.0-02P-14-00A(H); LCSC Part C5128812
U12: TJA1051T_3_1J; SOIC-8_L4.9-W3.9-P1.27-LS6.0-BL; MPN TJA1051T/3/1J; LCSC Part C38695
USB1: TYPE-C16PIN; USB-C-SMD_TYPE-C16PIN; MPN TYPE-C16PIN; LCSC Part C393939
W1, W2, W3, W4: SOLDERPAD-1P; SOLDERPAD-TH_3.0X1.5

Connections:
5V: C9.1, C16.2, C29.1, SB1.2, U6.3 (VIN), U8.6 (VOUT), U8.7 (FB), U12.3 (VCC)
12V: C17.2, CN3.1, CN5.1, CN6.1, D1.1 (K), D4.1 (K), D10.1 (C), Q4.2 (S), R26.2, U8.3 (VIN), U8.4 (EN), W2.1
120V: D9.1 (C), R10.2, U10.1, W1.1
CANH: CN2.2, R21.1, U12.7 (CANH)
CANL: CN2.1, R21.2, U12.6 (CANL)
COUPLER: CN6.2, D4.2 (A), Q3.3 (D)
COUPLER_GATE: Q3.2 (S), R28.2, R29.2
CP: CN2.4, R9.1
CP_SENSE: C7.1, R8.1, R9.2, U5.6 (AIN2)
D+: R31.2, U1.14 (IO20)
D-: R30.2, U1.13 (IO19)
DC_RELAY: CN3.2, CN5.2, D1.2 (A), Q1.3 (D)
EN: C2.2, C4.1, EN1.2, R1.2, U1.3 (EN)
GND: BOOT1.2, C1.1, C2.1, C3.1, C4.2, C7.2, C9.2, C10.2, C11.1, C12.2, C13.2, C14.2, C15.2, C16.1, C17.1, C20.2, C28.1, C29.2, CN1.1, CN2.3, D3.2 (A), D5.2, D10.2 (A), EMERGENCY1.3 (C), EMERGENCY1.4 (D), EN1.1, H1.1, H2.1, Q1.1 (G), Q2.1 (G), Q3.1 (G), R2.1, R3.1, R8.2, R12.1, R13.1, R14.1, R17.1, R20.1, R28.1, SETTING1.3 (C), SETTING1.4 (D), START1.3 (C), START1.4 (D), STOP1.3 (C), STOP1.4 (D), U1.1 (GND), U1.40 (GND), U1.41 (GND), U5.1 (ADDR), U5.3 (GND), U5.7 (AIN3), U6.1 (GND), U8.1 (GND), U8.2 (MODE_SYNC), U8.11 (EP), U12.2 (GND), U12.8 (S), USB1.1 (SHELL), USB1.2 (SHELL), USB1.3 (SHELL), USB1.4 (SHELL), USB1.A1B12 (GND), USB1.B1A12 (GND), W4.1
GND_BACK: C8.1, D9.2 (A), R11.1, U5.5 (AIN1), U10.2, W3.1
HV_DIV1: R10.1, R33.2
HV_DIV2: R33.1, R34.2
IO0: BOOT1.1, C11.2, R32.2, U1.27 (IO0)
IO5: D6.1 (A), U1.5 (IO5)
IO6: D7.1 (A), U1.6 (IO6)
IO7: D8.1 (A), U1.7 (IO7)
IO9: R16.1, U1.17 (IO9)
IO10: R29.1, U1.18 (IO10)
IO11: R19.1, U1.19 (IO11)
IO17: U1.10 (IO17), U12.1 (TXD)
IO18: U1.11 (IO18), U12.4 (RXD)
IO39: C12.1, STOP1.2 (B), U1.32 (IO39)
IO40: C14.1, EMERGENCY1.2 (B), U1.33 (IO40)
IO41: C15.1, SETTING1.2 (B), U1.34 (IO41)
IO42: START1.1 (A), U1.35 (IO42)
IO42_DEBOUNCE: C13.1, START1.2 (B)
LED_G_K: D7.2 (K), R14.2
LED_R_K: D8.2 (K), R12.2
LED_Y_K: D6.2 (K), R13.2
RELAY_GATE: Q1.2 (S), R19.2, R20.2
RXD0: H2.3, U1.36 (RXD0)
SCL: H1.3, R5.1, U1.8 (IO15), U5.10 (SCL)
SDA: H1.4, R6.1, U1.9 (IO16), U5.9 (SDA)
TXD0: H2.2, U1.37 (TXD0)
UD+: D5.1, USB1.A6 (DP1), USB1.B6 (DP2)
UD-: D5.3, USB1.A7 (DN1), USB1.B7 (DN2)
USB_CC1: R2.2, USB1.A5 (CC1)
USB_CC2: R3.2, USB1.B5 (CC2)
USB_DN_ESD: D5.4, R30.1
USB_DP_ESD: D5.6, R31.1
VBUS: D5.5, SB1.1, USB1.A4B9 (VBUS), USB1.B4A9 (VBUS)
VDD33: C1.2, C3.2, C10.1, C20.1, C28.2, H1.2, R1.1, R5.2, R6.2, R32.1, U1.2 (3V3), U5.8 (VDD), U6.2 (VOUT), U6.4 (VOUT), U12.5 (VIO)
VOUT_SENSE: C8.2, R11.2, R34.1, U5.4 (AIN0)
VP: CN1.2, D3.1 (C), Q4.3 (D)
VP_NGATE: Q2.2 (S), R16.2, R17.2
VP_PGATE: Q2.3 (D), Q4.1 (G), R26.1

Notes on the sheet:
MCU
USB
CAN
類比量測
繼電器
電磁鎖
VP 供電
指示燈
模組接線

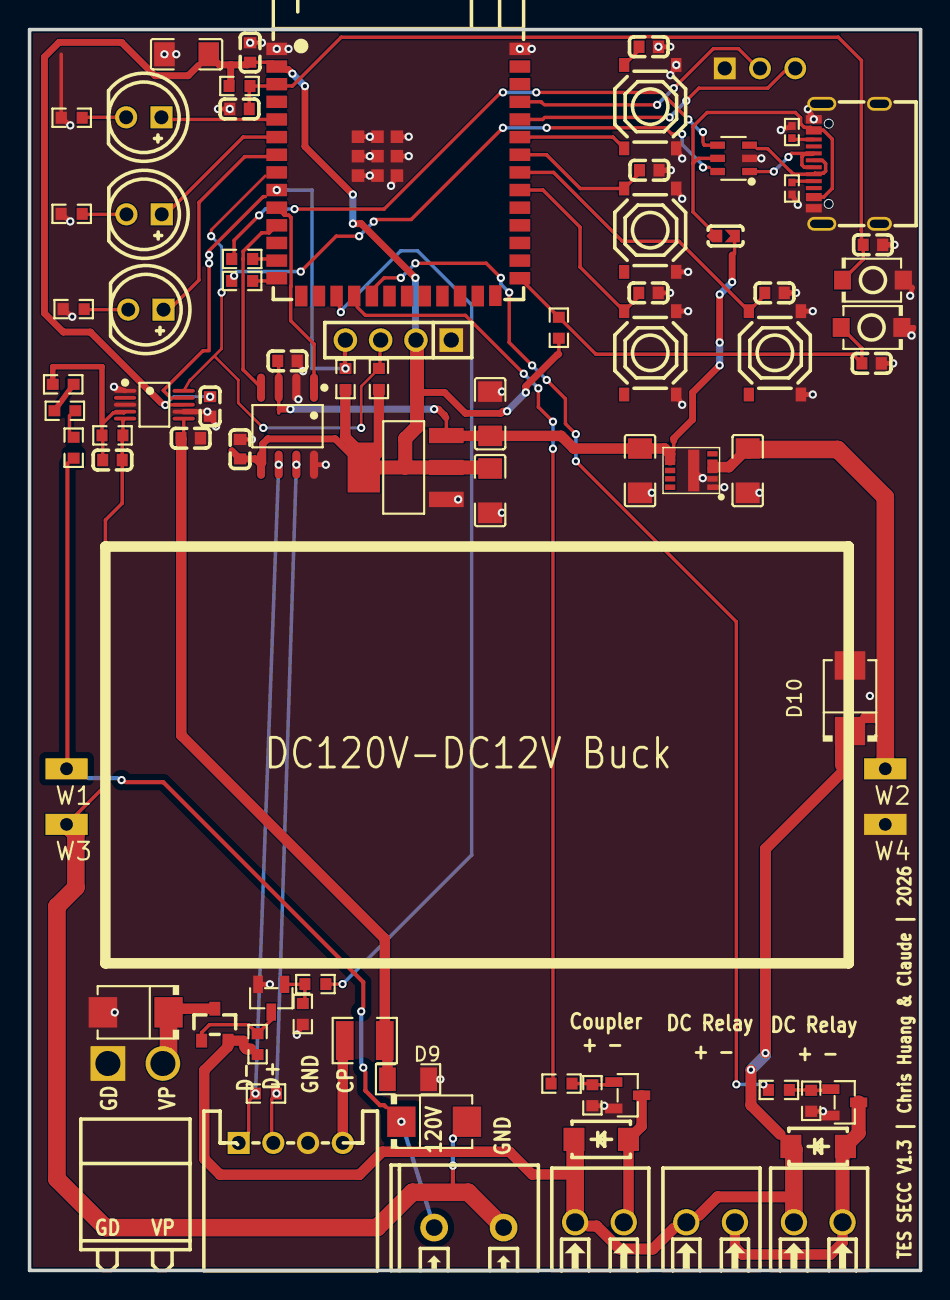
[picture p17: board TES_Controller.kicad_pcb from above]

Board: 2 copper layers, 64.1 x 89.3 mm, 81 parts (1 on the bottom side), 51 nets.

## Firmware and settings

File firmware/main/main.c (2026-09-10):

#include "globals.h"
#include "hal/hal_gpio.h"
#include "hal/hal_i2c.h"
#include "hal/hal_uart.h"
#include "hal/hal_nvs.h"
#include "drivers/can_driver.h"
#include "drivers/adc_driver.h"
#include "drivers/psu_driver.h"
#include "drivers/display_driver.h"
#include "drivers/led_driver.h"
#include "services/event_bus.h"
#include "services/config_svc.h"
#include "services/network_svc.h"
#include "services/notify_svc.h"
#include "services/log_svc.h"
#include "services/trace_svc.h"
#include "services/mqtt_svc.h"
#include "services/scheduler_svc.h"
#include "esp_log.h"
#include "freertos/FreeRTOS.h"
#include "freertos/task.h"
#include <stdatomic.h>
#include <string.h>

#define AUTO_VOLT_SETTLE_MS  1000   // ADC 穩定等待時間
#define AUTO_VOLT_MIN_V      40.0f
#define AUTO_VOLT_MAX_V     120.0f

// ── Boot logo (auto-voltage settle screen) ───────────────────────────────────
// Turtle mark on left (cx=30, cy=36), "Auto Setting Voltage..." on right.
// Shell: double circle ring. Lightning bolt inside. Head, 4 flippers, tail.

static void draw_auto_volt_screen(void)
{
    if (!display_driver_is_ok()) return;
    display_driver_clear();
    display_driver_set_color(1);

    // Shell — double ring
    display_driver_draw_circle(30, 36, 17);
    display_driver_draw_circle(30, 36, 13);

    // Head (filled disc)
    display_driver_draw_disc(30, 10, 5);

    // Neck
    display_driver_draw_line(30, 15, 30, 19);
    display_driver_draw_line(29, 15, 29, 19);

    // Flippers (filled triangles)
    display_driver_draw_triangle(13, 25,  0, 17,  2, 29);  // upper-left
    display_driver_draw_triangle(13, 47,  0, 39,  2, 51);  // lower-left
    display_driver_draw_triangle(47, 25, 60, 17, 58, 29);  // upper-right
    display_driver_draw_triangle(47, 47, 60, 39, 58, 51);  // lower-right

    // Tail
    display_driver_draw_triangle(30, 54, 25, 63, 35, 63);

    // Lightning bolt — two filled triangles forming a Z-zigzag
    // Upper part: top-right → middle-left → middle step
    display_driver_draw_triangle(35, 24, 27, 35, 31, 35);
    // Lower part: middle step → bottom
    display_driver_draw_triangle(27, 35, 31, 35, 23, 46);

    // Text (right side)
    display_driver_font_bold();
    display_driver_draw_str(65, 20, "Auto");
    display_driver_draw_str(65, 36, "Setting");
    display_driver_draw_str(65, 52, "Voltage...");

    display_driver_flush();
}

static const char *TAG = "main";

static void on_psu_paired(const uint8_t peer_mac[6])
{
    config_svc_set_psu(PSU_TRANSPORT_ESPNOW, peer_mac, true);
}

// ── Global definitions ───────────────────────────────────────────────────────

QueueHandle_t    g_can_rx_queue;
tes_snapshot_t   g_snapshot;
SemaphoreHandle_t g_snapshot_mutex;
atomic_bool      g_emergency_stop;
QueueHandle_t    g_btn_event_queue;
QueueHandle_t    g_display_btn_queue;
volatile bool    g_menu_open = false;
task_entry_t     g_tasks[G_TASK_MAX];
int              g_task_count = 0;

// spawn() 與 g_task_unregister_self() 之間有競態：
// 所有任務的優先權都高於 app_main（預設 1）且未綁核，因此 xTaskCreate 一回傳，
// 新任務可能已經在另一顆核心上執行完畢。會自我刪除的任務（mqtt/ota/log 在未設定
// 或訂閱失敗時）就會在自己還沒被登記進 g_tasks 時呼叫 unregister，掃不到而空手返回；
// 等 app_main 回來，反而把一個已失效的 handle 寫進表裡。
// task_monitor 之後對它呼叫 uxTaskGetStackHighWaterMark 就是對已釋放的 TCB
// 解參考 —— 實測會 LoadProhibited（EXCVADDR=0）重開機。
//
// 解法：提早結束、還來不及被登記的任務先記進 s_exited，spawn() 登記時據此抵銷。
// 只比對指標、不解參考，因此 handle 已失效也是安全的。
static portMUX_TYPE s_task_mux = portMUX_INITIALIZER_UNLOCKED;
static TaskHandle_t s_exited[G_TASK_MAX];
static int          s_exited_count = 0;

void g_task_unregister_self(void)
{
    TaskHandle_t me = xTaskGetCurrentTaskHandle();
    taskENTER_CRITICAL(&s_task_mux);
    for (int i = 0; i < g_task_count; i++) {
        if (g_tasks[i].handle == me) {
            g_tasks[i].handle = NULL;
            taskEXIT_CRITICAL(&s_task_mux);
            return;
        }
    }
    // 還沒被登記 —— 留給 spawn() 抵銷
    if (s_exited_count < G_TASK_MAX) s_exited[s_exited_count++] = me;
    taskEXIT_CRITICAL(&s_task_mux);
}

// 建立任務並登記到 g_tasks，讓 task_monitor 能回報堆疊餘裕
static void spawn(TaskFunction_t fn, const char *name, uint32_t stack, UBaseType_t prio)
{
    TaskHandle_t h = NULL;
    if (xTaskCreate(fn, name, stack, NULL, prio, &h) != pdPASS) {
        ESP_LOGE(TAG, "xTaskCreate(%s) failed", name);
        return;
    }
    taskENTER_CRITICAL(&s_task_mux);
    bool already_exited = false;
    for (int i = 0; i < s_exited_count; i++) {
        if (s_exited[i] == h) {
            already_exited   = true;
            s_exited[i]      = s_exited[--s_exited_count];
            break;
        }
    }
    if (!already_exited && g_task_count < G_TASK_MAX) {
        g_tasks[g_task_count].name   = name;
        g_tasks[g_task_count].handle = h;
        g_task_count++;
    }
    taskEXIT_CRITICAL(&s_task_mux);
}

// ── Task forward declarations ────────────────────────────────────────────────

void task_can_rx   (void *arg);
void task_tes_sm   (void *arg);
void task_hal_poll (void *arg);
void task_display  (void *arg);
void task_network  (void *arg);
void task_ota      (void *arg);
void task_notify   (void *arg);
void task_log      (void *arg);
void task_mqtt      (void *arg);
void task_scheduler (void *arg);
void task_monitor   (void *arg);

// ── Entry point ──────────────────────────────────────────────────────────────

void app_main(void)
{
    ESP_LOGI(TAG, "TES Charger V3 starting");

    // HAL init
    ESP_ERROR_CHECK(hal_nvs_init());
    hal_gpio_init();
    ESP_ERROR_CHECK(hal_i2c_init());
    ESP_ERROR_CHECK(hal_uart_psu_init());

    // Driver init
    ESP_ERROR_CHECK(can_driver_init());
    // ADC 缺席不應該讓整台機器開機循環（與 display_driver 一致採非致命處理）。
    // 無 ADS1115 時 CP 與輸出電壓讀值維持 0，仍可用手動 START + PSU 回報值充電。
    if (adc_driver_init() != ESP_OK) {
        ESP_LOGE(TAG, "ADS1115 init failed — CP/voltage sensing unavailable");
    }
    ESP_ERROR_CHECK(psu_driver_init());
    display_driver_init();   // non-fatal if OLED absent
    led_driver_init();

    // Services init
    event_bus_init();
    ESP_ERROR_CHECK(config_svc_init());
    notify_svc_init();
    log_svc_init();
    // trace buffer 配置在 PSRAM；失敗只會停用曲線/Log，不影響充電
    if (trace_svc_init() != ESP_OK) {
        ESP_LOGW(TAG, "trace_svc unavailable — charge curve/log disabled");
    }
    mqtt_svc_init();
    ESP_ERROR_CHECK(scheduler_svc_init());

    // Auto-voltage: 等待 ADC 穩定後讀一次電壓，更新 max_voltage（僅 RAM）
    if (config_svc_get()->auto_voltage) {
        ESP_LOGI(TAG, "auto-voltage: waiting %dms for ADC to settle", AUTO_VOLT_SETTLE_MS);
        draw_auto_volt_screen();
        vTaskDelay(pdMS_TO_TICKS(AUTO_VOLT_SETTLE_MS));
        float v = adc_driver_read_voltage();
        if (v >= AUTO_VOLT_MIN_V && v <= AUTO_VOLT_MAX_V) {
            config_svc_override_voltage((uint16_t)(v * 10.0f + 0.5f));
        } else {
            ESP_LOGW(TAG, "auto-voltage: ADC read %.1fV out of range, keeping NVS value", v);
        }
    }

    ESP_ERROR_CHECK(network_svc_init());

    // IPC objects
    g_can_rx_queue      = xQueueCreate(16, sizeof(can_frame_t));
    g_snapshot_mutex    = xSemaphoreCreateMutex();
    g_btn_event_queue   = xQueueCreate(8, sizeof(uint8_t));
    g_display_btn_queue = xQueueCreate(8, sizeof(uint8_t));
    atomic_init(&g_emergency_stop, false);

    // Spawn tasks (priority 15 = highest used here)
    // can_rx 需要 4KB：迴圈裡的 can_driver_service() 在 TWAI 進入 error-passive／
    // bus-off 時會呼叫 ESP_LOGW，而 esp_log 的 vprintf 一次就要 1KB 以上。
    // 2KB 時只要按下 START（開始送 0x508／0x509 而匯流排無 ACK）就必定溢位重開機。
    spawn(task_can_rx,   "can_rx",   4096,  15);
    // tes_sm 需要 8KB：除了 inputs/outputs/snapshot，trace 的變動 Log 會呼叫
    // vsnprintf("%f")，newlib 的浮點格式化本身就要好幾百 bytes。
    // 4KB 時按下 START 會堆疊溢位重開機。
    spawn(task_tes_sm,   "tes_sm",   8192,  12);
    spawn(task_hal_poll, "hal_poll", 4096,  10);
    spawn(task_display,  "display",  4096,   4);
    spawn(task_network,  "network",  12288,  3);
    spawn(task_ota,      "ota",      16384,  2);
    spawn(task_notify,   "notify",   6144,   2);
    spawn(task_mqtt,     "mqtt",     8192,   2);
    spawn(task_scheduler,"sched",    4096,   2);
    spawn(task_log,      "task_log", 3072,   1);
    spawn(task_monitor,  "monitor",  4096,   1);

    network_svc_start();   // 這裡才真正呼叫 esp_wifi_start()

    // ESP-NOW transport init — 必須在 esp_wifi_start() 之後。
    // esp_now_init() 要求 WiFi 已經啟動；放在 network_svc_init() 之後會失敗，
    // psu_driver 會靜默 fallback 回 UART，ESP-NOW 永遠不會生效。
    {
        const charger_config_t *cfg = config_svc_get();
        psu_driver_set_pair_callback(on_psu_paired);
        esp_err_t r = psu_driver_set_transport(
            (psu_transport_t)cfg->psu_transport,
            cfg->psu_paired ? cfg->psu_peer_mac : NULL
        );
        if (r != ESP_OK) {
            ESP_LOGE(TAG, "PSU transport init failed: %s — falling back to UART",
                     esp_err_to_name(r));
        }
    }

    ESP_LOGI(TAG, "all tasks started");
}

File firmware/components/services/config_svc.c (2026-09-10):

#include "services/config_svc.h"
#include "hal/hal_nvs.h"
#include "esp_log.h"
#include "esp_mac.h"
#include "freertos/FreeRTOS.h"
#include "freertos/task.h"
#include <string.h>

static const char *TAG = "config_svc";

#define NVS_NS          "tes_cfg"
#define NVS_KEY_MAX_V   "max_v"
#define NVS_KEY_MAX_A   "max_a"
#define NVS_KEY_SOC     "target_soc"
#define NVS_KEY_SSID    "wifi_ssid"
#define NVS_KEY_PASS    "wifi_pass"
#define NVS_KEY_STA_EN  "sta_en"
#define NVS_KEY_BEACON  "beacon"
#define NVS_KEY_AUTO_V  "auto_v"
#define NVS_KEY_STOP_M  "stop_m"
#define NVS_KEY_STOP_V  "stop_v"
#define NVS_KEY_TIMER_M "timer_m"
#define NVS_KEY_NOTIFY     "notify_url"
#define NVS_KEY_MQTT_URL      "mqtt_url"
#define NVS_KEY_MQTT_TOPIC    "mqtt_topic"
#define NVS_KEY_MQTT_CMD      "mqtt_cmd"
#define NVS_KEY_SCHED_EN      "sched_en"
#define NVS_KEY_SCHED_START   "sched_start"
#define NVS_KEY_SCHED_STOP_EN "sched_stop_en"
#define NVS_KEY_SCHED_STOP    "sched_stop"
#define NVS_KEY_AUTO_START    "auto_s"
#define NVS_KEY_PSU_TRANS     "psu_trans"
#define NVS_KEY_PSU_MAC       "psu_mac"
#define NVS_KEY_DEV_NAME      "dev_name"

#define DEFAULT_MAX_V   1000   // 100.0 V
#define DEFAULT_MAX_A   100    // 10.0 A
#define DEFAULT_SOC     80
#define DEFAULT_STOP_V  1000   // 100.0 V
#define DEFAULT_TIMER_M 120    // 120 min

static charger_config_t s_cfg;

// 保護 s_cfg 的多欄位更新。setter 由 HTTP / display task 呼叫，
// 讀取端（task_tes_sm）每 10ms 會取用。臨界區內只有 memcpy，非常短。
static portMUX_TYPE s_cfg_mux = portMUX_INITIALIZER_UNLOCKED;

#define CFG_WRITE_BEGIN()  taskENTER_CRITICAL(&s_cfg_mux)
#define CFG_WRITE_END()    taskEXIT_CRITICAL(&s_cfg_mux)

void config_svc_get_copy(charger_config_t *out)
{
    if (!out) return;
    taskENTER_CRITICAL(&s_cfg_mux);
    memcpy(out, &s_cfg, sizeof(*out));
    taskEXIT_CRITICAL(&s_cfg_mux);
}

esp_err_t config_svc_init(void)
{
    memset(&s_cfg, 0, sizeof(s_cfg));

    // 裝置識別碼：MAC 後 3 bytes。efuse 讀取，不需要 WiFi 已啟動。
    // 同網段兩台機器就是靠這組值區分 mDNS 主機名與 AP SSID。
    {
        uint8_t mac[6] = {0};
        esp_read_mac(mac, ESP_MAC_WIFI_STA);
        snprintf(s_cfg.device_id, sizeof(s_cfg.device_id),
                 "%02x%02x%02x", mac[3], mac[4], mac[5]);
    }
    if (hal_nvs_get_str(NVS_NS, NVS_KEY_DEV_NAME,
                        s_cfg.device_name, sizeof(s_cfg.device_name)) != ESP_OK) {
        s_cfg.device_name[0] = '\0';
    }

    uint32_t tmp;
    s_cfg.max_voltage_01v = (hal_nvs_get_u32(NVS_NS, NVS_KEY_MAX_V, &tmp) == ESP_OK)
                            ? (uint16_t)tmp : DEFAULT_MAX_V;
    s_cfg.max_current_01a = (hal_nvs_get_u32(NVS_NS, NVS_KEY_MAX_A, &tmp) == ESP_OK)
                            ? (uint16_t)tmp : DEFAULT_MAX_A;

    int32_t soc;
    s_cfg.target_soc = (hal_nvs_get_i32(NVS_NS, NVS_KEY_SOC, &soc) == ESP_OK)
                       ? (int8_t)soc : DEFAULT_SOC;

    if (hal_nvs_get_str(NVS_NS, NVS_KEY_SSID, s_cfg.wifi_ssid, sizeof(s_cfg.wifi_ssid)) != ESP_OK) {
        s_cfg.wifi_ssid[0] = '\0';
    }
    if (hal_nvs_get_str(NVS_NS, NVS_KEY_PASS, s_cfg.wifi_pass, sizeof(s_cfg.wifi_pass)) != ESP_OK) {
        s_cfg.wifi_pass[0] = '\0';
    }

    // 預設 true —— 舊機器升級上來時 NVS 沒有這個鍵，必須維持原本會連線的行為，
    // 否則 OTA 之後全部退回 AP 模式，使用者會以為機器壞了。
    bool sta_en;
    s_cfg.sta_enabled = (hal_nvs_get_bool(NVS_NS, NVS_KEY_STA_EN, &sta_en) == ESP_OK) ? sta_en : true;

    bool beacon;
    s_cfg.beacon_unlocked = (hal_nvs_get_bool(NVS_NS, NVS_KEY_BEACON, &beacon) == ESP_OK) && beacon;

    bool auto_v;
    s_cfg.auto_voltage = (hal_nvs_get_bool(NVS_NS, NVS_KEY_AUTO_V, &auto_v) == ESP_OK) && auto_v;

    {
        uint32_t tmp;
        s_cfg.stop_mode = (hal_nvs_get_u32(NVS_NS, NVS_KEY_STOP_M, &tmp) == ESP_OK && tmp <= 2)
                          ? (stop_mode_t)tmp : STOP_MODE_SOC;
        s_cfg.stop_voltage_01v = (hal_nvs_get_u32(NVS_NS, NVS_KEY_STOP_V, &tmp) == ESP_OK)
                                 ? (uint16_t)tmp : DEFAULT_STOP_V;
        s_cfg.charge_timer_min = (hal_nvs_get_u32(NVS_NS, NVS_KEY_TIMER_M, &tmp) == ESP_OK
                                  && tmp >= 1 && tmp <= 600)
                                 ? (uint16_t)tmp : DEFAULT_TIMER_M;
    }

    if (hal_nvs_get_str(NVS_NS, NVS_KEY_NOTIFY, s_cfg.notify_url, sizeof(s_cfg.notify_url)) != ESP_OK) {
        s_cfg.notify_url[0] = '\0';
    }

    if (hal_nvs_get_str(NVS_NS, NVS_KEY_MQTT_URL, s_cfg.mqtt_broker_url, sizeof(s_cfg.mqtt_broker_url)) != ESP_OK) {
        s_cfg.mqtt_broker_url[0] = '\0';
    }
    if (hal_nvs_get_str(NVS_NS, NVS_KEY_MQTT_TOPIC, s_cfg.mqtt_topic_prefix, sizeof(s_cfg.mqtt_topic_prefix)) != ESP_OK) {
        // 預設帶上 device_id：兩台機器共用同一個 broker 時，
        // 舊的固定值 "tes/charger" 會讓兩邊互相覆蓋彼此的狀態與指令。
        // 已經設定過 MQTT 的裝置 NVS 裡有值，不受影響。
        snprintf(s_cfg.mqtt_topic_prefix, sizeof(s_cfg.mqtt_topic_prefix),
                 "tes/%s", s_cfg.device_id);
    }
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

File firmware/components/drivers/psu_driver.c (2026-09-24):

#include "drivers/psu_driver.h"
#include "hal/hal_uart.h"
#include "esp_log.h"
#include "esp_now.h"
#include "esp_wifi.h"
#include "freertos/FreeRTOS.h"
#include "freertos/queue.h"
#include <string.h>

#define PSU_UART_TIMEOUT_TICKS    300   // 300 × 10ms = 3s   (UART，有線可寬鬆)
#define PSU_ESPNOW_TIMEOUT_TICKS  200   // 200 × 10ms = 2s  (ESP-NOW；MAC-ACK 連敗仍 30ms 快斷)
#define PSU_ESPNOW_FAIL_LIMIT       3   // 連續 MAC-ACK 失敗 N 次 → 立即標記斷線
#define PSU_SET_MIN_TICKS          50   //  50 × 10ms = 500ms：同值 SET 最短發送間隔（UART 與 ESP-NOW 共用）
#define PSU_HELLO_INTERVAL_TICKS  100   // 100 × 10ms = 1s：已連線但還不知道節點能力時，多久問一次
#define PSU_ESPNOW_RSSI_WARN      -80   // dBm，低於此值印 LOGW
#define PAIRING_TIMEOUT_TICKS    1000   // 1000 × 10ms = 10s pairing window

static const char *TAG = "psu_driver";

// ── Shared state ──────────────────────────────────────────────────────────────

static psu_status_t    s_status           = { .status_age_ms = UINT32_MAX };
static uint32_t        s_poll_ticks       = 0;
static uint32_t        s_last_valid_ticks = 0;   // 最後一個有效訊框（任何類型）
static uint32_t        s_last_st_ticks    = 0;   // 最後一筆 ST
static bool            s_have_st          = false;
static uint32_t        s_last_hello_ticks = 0;
static psu_transport_t s_transport        = PSU_TRANSPORT_UART;

// s_status 由 task_hal_poll 寫入，由 task_tes_sm / HTTP / display 讀取。
// struct copy 不是原子操作，沒有保護時可能讀到「新電壓 + 舊電流」的組合。
static portMUX_TYPE s_status_mux = portMUX_INITIALIZER_UNLOCKED;

// ── UART state ────────────────────────────────────────────────────────────────

static char s_rx_buf[PSU_LINK_MAX_LINE];
static int  s_rx_len     = 0;
static bool s_rx_discard = false;   // 行太長：丟到下一個 '\n' 為止，不要把後半段當成新的一行

// ── ESP-NOW state ─────────────────────────────────────────────────────────────

typedef struct {
    char    data[PSU_LINK_MAX_LINE];
    int     len;
    uint8_t src_mac[6];
} espnow_rx_item_t;

static QueueHandle_t      s_espnow_rx_q = NULL;
static bool               s_has_peer    = false;
static uint8_t            s_peer_mac[6] = {0};
static volatile bool      s_pairing     = false;
static uint32_t           s_pairing_end = 0;
static psu_pair_done_cb_t s_pair_cb     = NULL;

// ESP-NOW 品質追蹤
static volatile uint8_t  s_send_fail_streak = 0;   // 連續 MAC-ACK 失敗次數（WiFi task 寫）
static volatile int8_t   s_last_rssi        = 0;   // 最後收到的 RSSI（WiFi task 寫）
static bool              s_rssi_warned      = false;

// SET 節流與序號（同 task_tes_sm 呼叫，不跨 task）
static float    s_cached_v       = -1.f;  // 最後實際發出的電壓 setpoint
static float    s_cached_a       = -1.f;  // 最後實際發出的電流 setpoint
static uint32_t s_last_v_tx_tick = 0;     // 發出時的 s_poll_ticks
static uint32_t s_last_a_tx_tick = 0;
static uint16_t s_set_seq        = 0;

static const uint8_t BCAST_MAC[6] = {0xFF, 0xFF, 0xFF, 0xFF, 0xFF, 0xFF};

// ── Link state ────────────────────────────────────────────────────────────────

// 斷線時連節點身分一起清掉：下一個連上的可能是另一個節點（或同一個重開機、換過韌體）
static void link_down(void)
{
    taskENTER_CRITICAL(&s_status_mux);
    s_status.connected  = false;
    s_status.voltage    = 0.f;
    s_status.current    = 0.f;
    s_status.caps_known = false;
    s_status.mode       = PSU_MODE_UNKNOWN;
    s_status.flags      = 0;
    taskEXIT_CRITICAL(&s_status_mux);
    s_have_st = false;
}

static void link_alive(void)
{
    if (!s_status.connected) ESP_LOGI(TAG, "PSU connected");
    taskENTER_CRITICAL(&s_status_mux);
    s_status.connected = true;
    taskEXIT_CRITICAL(&s_status_mux);
    s_last_valid_ticks = s_poll_ticks;
}

static void send_line(const char *buf, size_t len)
{
    if (s_transport == PSU_TRANSPORT_ESPNOW) {
        if (s_has_peer) esp_now_send(s_peer_mac, (const uint8_t *)buf, len);
    } else {
        hal_uart_psu_write((const uint8_t *)buf, len);
    }
}

static void send_msg(const psu_msg_t *m)
{
    char buf[PSU_LINK_MAX_LINE];
    size_t n = psu_link_encode(m, buf, sizeof buf);
    if (n > 0) send_line(buf, n);
}

// ── Incoming messages ─────────────────────────────────────────────────────────

static void on_status(const psu_msg_status_t *st)
{
    // 電壓／電流無效時填 0：狀態機以「psu_voltage > 0」判斷 PSU 是否在回報，
    // 否則改用 ADC 量測。舊協定只在輸出中送 V=、待機送 HB，行為要跟它一致。
    bool v_ok = (st->flags & PSU_ST_V_VALID) != 0;
    bool i_ok = (st->flags & PSU_ST_I_VALID) != 0;
    taskENTER_CRITICAL(&s_status_mux);
    s_status.voltage    = v_ok ? (float)st->v_cv / 100.0f : 0.f;
    s_status.current    = i_ok ? (float)st->i_ca / 100.0f : 0.f;
    s_status.mode       = st->mode;
    s_status.flags      = st->flags;
    s_status.status_seq = st->seq;
    taskEXIT_CRITICAL(&s_status_mux);
    s_last_st_ticks = s_poll_ticks;
    s_have_st       = true;
}

static void on_cap(const psu_msg_cap_t *cap)
{
    bool first = !s_status.caps_known;
    taskENTER_CRITICAL(&s_status_mux);
    s_status.caps_known = true;
    s_status.proto_ver  = cap->proto_ver;
    s_status.node_type  = cap->node_type;
    s_status.caps       = cap->caps;
    s_status.v_max_cv   = cap->v_max_cv;
    s_status.i_max_ca   = cap->i_max_ca;
    s_status.fw_ver     = cap->fw_ver;
    taskEXIT_CRITICAL(&s_status_mux);
    if (first) {
        ESP_LOGI(TAG, "PSU node: type=%u caps=0x%04X max=%u.%02uV/%u.%02uA fw=%u proto=%u",
                 cap->node_type, cap->caps,
                 cap->v_max_cv / 100u, cap->v_max_cv % 100u,
                 cap->i_max_ca / 100u, cap->i_max_ca % 100u,
                 cap->fw_ver, cap->proto_ver);
    }
    if (cap->proto_ver != PSU_LINK_PROTO_VER) {
        ESP_LOGW(TAG, "PSU node speaks protocol v%u, we speak v%u",
                 cap->proto_ver, PSU_LINK_PROTO_VER);
    }
}

static void on_ack(const psu_msg_ack_t *ack)
{
    taskENTER_CRITICAL(&s_status_mux);
    s_status.last_ack_seq    = ack->seq;
    s_status.last_ack_result = ack->result;
    taskEXIT_CRITICAL(&s_status_mux);
    if (ack->result != PSU_ACK_OK) {
        ESP_LOGW(TAG, "PSU rejected SET #%u (result %u)", ack->seq, ack->result);
    }
}

static void handle_line(const char *line, size_t len)
{
    psu_msg_t m;
    psu_link_result_t r = psu_link_decode(line, len, &m);

    switch (r) {
    case PSU_LINK_OK:
        break;
    case PSU_LINK_NOT_FRAME:
        return;   // 節點的開機訊息、文字指令回應…不屬於本協定
    case PSU_LINK_BAD_CRC:
        taskENTER_CRITICAL(&s_status_mux);
        s_status.rx_crc_errors++;
        taskEXIT_CRITICAL(&s_status_mux);
        return;
    default:
        taskENTER_CRITICAL(&s_status_mux);
        s_status.rx_bad_frames++;
        taskEXIT_CRITICAL(&s_status_mux);
        ESP_LOGD(TAG, "unusable frame (%d): %.*s", (int)r, (int)len, line);
        return;
    }

    taskENTER_CRITICAL(&s_status_mux);
    s_status.rx_frames++;
    taskEXIT_CRITICAL(&s_status_mux);

    switch (m.type) {
    case PSU_MSG_STATUS: link_alive(); on_status(&m.u.status); break;
    case PSU_MSG_CAP:    link_alive(); on_cap(&m.u.cap);       break;
    case PSU_MSG_ACK:    link_alive(); on_ack(&m.u.ack);       break;
    default:             break;   // HELO / SET 是控制板送出的方向，收到就忽略
    }
}
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

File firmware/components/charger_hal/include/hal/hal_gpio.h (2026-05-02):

#pragma once
#include <stdbool.h>
#include <driver/gpio.h>

// GPIO 腳位配置（對應 V2 Config.h）
#define PIN_BTN_START       GPIO_NUM_42
#define PIN_BTN_STOP        GPIO_NUM_39
#define PIN_BTN_EMERGENCY   GPIO_NUM_40
#define PIN_BTN_SETTING     GPIO_NUM_41

#define PIN_LED_STANDBY     GPIO_NUM_5   // 橘燈
#define PIN_LED_CHARGING    GPIO_NUM_6   // 綠燈
#define PIN_LED_ERROR       GPIO_NUM_7   // 紅燈

#define PIN_RELAY_CHARGE    GPIO_NUM_11  // 主充電繼電器
#define PIN_SOLENOID_LOCK   GPIO_NUM_10  // 電磁鎖
#define PIN_RELAY_VP        GPIO_NUM_9   // VP 繼電器

typedef enum {
    BTN_START = 0,
    BTN_STOP,
    BTN_EMERGENCY,
    BTN_SETTING,
} button_id_t;

void hal_gpio_init(void);

// 按鈕：active-low，debounce 由 task_hal_poll 處理
bool hal_gpio_button_raw(button_id_t btn);

// 繼電器與輸出控制
void hal_gpio_relay_set       (bool on);
void hal_gpio_coupler_lock_set(bool lock);
void hal_gpio_vp_relay_set    (bool on);
bool hal_gpio_relay_get       (void);

// LED（直接 GPIO，pattern 由 led_driver 管理）
void hal_gpio_led_standby_set (bool on);
void hal_gpio_led_charging_set(bool on);
void hal_gpio_led_error_set   (bool on);

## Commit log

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2025-09-22 v2.3.0
    Fix current report issue、Add vehicle request current display、Add Error stop reason display
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2026-05-01 PSU Bug fixed,Basic function test ok
    [psu_driver.c, task_tes_sm.c]
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2026-05-01 Add Network and fix logic bug
    [task_tes_sm.c]
2026-05-02 V3 feature complete: OTA, 5F0 fix, GitHub Actions CI/CD
    - ota_svc: HTTPS cert bundle, error state tracking, default GitHub Releases URL
    - network_svc: POST /ota endpoint, firmware version + OTA state in /status
    - web UI: OTA card with one-click update and progress display
    - tes_sm: 5F0 post-charge emergency auto-recovery (5s timeout, emergency_hw_triggered)
    - .github/workflows/build-v3.yml: matrix build + automated Release on tag push
    - docs/: GitHub Pages web flasher (ESP Web Tools) + manifest.json
    - CLAUDE.md: progress, release flow, OTA flow all updated
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2026-05-02 Add auto-voltage feature with user toggle
    When enabled, the SM uses the vehicle's max_charge_voltage (CAN 0x501)
    as the PSU voltage target instead of the user-configured max_voltage_01v.
    The manual setting becomes a safety cap in auto mode. Default: off.
    - tes_sm_inputs_t: add auto_voltage bool
    - check_battery_compatibility: auto mode skips manual voltage limit check,
    targets min(BMS max_charge_voltage, max_voltage_01v)
    - config_svc: new auto_v NVS key + config_svc_set_auto_voltage()
    - display_svc: MENU_ITEM_AUTO_VOLTAGE at top of settings menu;
    Max Volt label changes to "V Cap" when auto is ON
    - task_tes_sm: pass cfg->auto_voltage to inputs each tick
    - network_svc: auto_voltage in GET/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
    [config_svc.c, task_tes_sm.c]
2026-05-02 Fix auto-voltage: use ADC reading instead of BMS CAN data
    Auto-voltage detects the PSU's configured output voltage via the
    high-precision ADS1115 ADC while in IDLE state, eliminating the need
    for the user to manually enter the max voltage. The NVS-stored value
    acts as fallback when ADC reads out-of-range (< 40V or > 120V).
    Logic lives in task_tes_sm.c (not in tes_sm.c) so the pure-functional
    SM is unaware of the auto-voltage policy. tes_sm_inputs_t unchanged.
    [task_tes_sm.c]
2026-05-02 Auto-voltage: one-shot ADC read at boot with 1s settle delay
    When auto_voltage is enabled, app_main waits 1s after ADC init for the
    PSU output to stabilise, then reads the voltage once and applies it to
    max_voltage_01v in RAM (NVS untouched). If ADC reads out of range the
    NVS value is kept as-is. No delay occurs when the feature is off.
    [config_svc.c, main.c, task_tes_sm.c]
2026-05-02 Add turtle boot logo on auto-voltage settle screen
    During the 1s ADC settle delay, draws the TES turtle mark on the OLED:
    - Double-ring shell with lightning bolt (Z-zigzag, two filled triangles)
    - Filled head disc + neck lines
    - Four filled flipper triangles + tail triangle
    - "Auto / Setting / Voltage..." bold text on the right
    Added draw_circle, draw_disc, draw_line, draw_triangle to display_driver.
    [display_driver.c, main.c]
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2026-05-02 Show only active stop condition in OLED menu and web UI
    OLED menu skips Target SOC when voltage-stop mode is active, and
    skips Stop Voltage when SOC-stop mode is active, using a dynamic
    visible-items list to keep cursor/scroll consistent. Web UI hides
    the SOC field when voltage mode is selected and vice versa.
2026-05-02 Add manual firmware upload via POST /ota/upload and web UI
    Web UI gets a file picker and upload button in the OTA card.
    Backend receives the binary in 4 KB chunks, writes directly to
    the OTA partition via esp_ota_* APIs, then validates and reboots.
    Progress is shared with the existing status polling mechanism.
    recv_wait_timeout raised to 30 s for slow WiFi transfers.
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2026-05-04 Add v3.1.0-beta: notify, log, PWA, WiFi scan, offline fix, about page
    New services:
    - notify_svc: ntfy.sh-compatible webhook push on charge start/complete/fault/emergency
    - log_svc: last 20 charge sessions stored as NVS blob; GET /history API
    New REST endpoints: GET /history, GET /wifi/scan, POST /notify/test
    GET /manifest.json, GET /sw.js, GET /icon.svg (PWA support)
    Web UI additions:
    - PWA: manifest, service worker, homescreen install support
    - ntfy.sh guided setup with auto-generated topic, deep-link subscribe
    - WiFi scan button + dropdown
    - Phone WiFi switch button (iOS/Android deep links)
    - Charge history table (duration, Wh, SOC, stop reason)
    - About: firmware version + author in OTA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
    [config_svc.c, hal_nvs.c]
2026-05-06 Add v3.2.0-beta: MQTT remote monitoring + Cloud PWA
    - mqtt_svc: esp-mqtt client, publish status (10s charging / 30s idle),
    subscribe cmd topic for remote start/stop via g_btn_event_queue
    - config_svc: add mqtt_broker_url / mqtt_topic_prefix fields + NVS persistence
    - network_svc: GET /mqtt/link returns pre-built Cloud PWA URL with WS port
    mapping (HiveMQ→8000, Mosquitto→8080, others→8083); POST /config handles
    mqtt fields; GET /config exposes mqtt fields
    - Web UI: MQTT settings card (broker URL + topic prefix), monitor card with
    copy/open link buttons, loadMqttLink() on page load
    - docs/monitor.html: Cloud PWA (MQTT.js WebSocket), auto-connect from URL
    fragment or localStorag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
    [config_svc.c, main.c]
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2026-05-06 Add full CAN diagnostic display to Web UI (all 6 messages)
    - tes_types.h: expand tes_can_diag_t to cover all 6 CAN messages
    (0x500/501/5F0 RX, 0x508/509/5F8 TX) with decoded field names
    - task_tes_sm.c: store 0x5F0 raw flags; cache last sent 0x508/509/5F8
    frames; inject complete CAN diag into snapshot each tick
    - network_svc.c: GET /status can{} object now contains all 21 fields
    - index.html: CAN diagnostic card redesigned with direction badges
    (← RX green / TX → blue), message ID labels, and all decoded fields
    as human-readable values; bit flags shown as coloured indicator dots
    [task_tes_sm.c]
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2026-05-07 Add STOP_MODE_TIMER: charge timer stop + OLED/Web UI display fixes
    - config_svc: add charge_timer_min field (NVS key timer_m, default 120 min)
    - config_svc_set_stop: accept charge_timer_min as third parameter
    - tes_sm_inputs_t: add charge_timer_min field
    - tes_sm run_monitoring: check elapsed_seconds >= timer_min * 60 for TIMER mode
    - task_tes_sm: pass charge_timer_min from config to SM inputs
    - display_svc: STOP_MODE_TIMER menu item (Charge Timer, 10-600 min, ±10/±30 min)
    Stop Mode cycles SOC → Volt → Timer → SOC
    Timer mode status screen: row2 = voltage/current, row3 = SOC + elapsed/target
    Volt mode status screen: row3 now includes remaining time (was missing)
    - network_svc: /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
    [config_svc.c, task_tes_sm.c]
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2026-05-07 Fix charge timer min validation: lower limit from 10 to 1 minute
    Values < 10 min were silently rejected by network_svc and config_svc,
    causing the timer to stay at the previous value (default 120 min).
    No error was returned to the client, making it appear the setting worked.
    Affected: network_svc.c (POST /config validation), config_svc.c (NVS read),
    display_svc.c (OLED menu clamp), web/index.html (input min/step attributes).
    [config_svc.c]
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2026-05-09 Add scheduled charging feature (v3.4.0)
    Implements scheduler_svc with NTP time sync (UTC+8, pool.ntp.org) and
    daily charging window edge-crossing detection. Fires EVT_BUTTON_START/
    STOP to g_btn_event_queue at configured times; supports overnight windows
    (e.g. 23:00-06:00) and auto-resumes mid-window after reboot when stop is
    enabled. OLED menu adds Scheduler ON/OFF toggle; Web UI adds time pickers,
    stop-enable checkbox, and live NTP sync status. Config persisted to NVS
    (sched_en/sched_start/sched_stop_en/sched_stop). /status returns
    ntp_synced and local_time; /config GET/POST support all four fields.
    [config_svc.c, main.c]
2026-05-09 Add Beta auto-start feature: VP always on, auto-trigger on CP/CAN edge
    When auto_start is enabled, the VP relay stays on in IDLE so vehicle
    electronics remain powered. Charging starts automatically on a CP
    OFF→ON edge (plug-in) or a CAN 0x500 bit0 rising edge (BMS permit),
    without requiring a manual START press.
    Safety constraints:
    - fault_latched blocks auto-trigger; fault requires manual START
    - charge_complete_latched prevents re-trigger until CP is stably OFF
    for two consecutive readings, then reconnect starts a new session
    - Emergency stop always forces VP off regardless of setting
    Config: NVS key "auto_s" (bool). Exposed via /config GET/POST,
    OLED menu "[Beta]Auto: ON/OFF", and W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
    [config_svc.c, task_tes_sm.c]
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2026-05-17 Add ESP-NOW PSU transport, connection monitoring, and charging safety
    - psu_driver: add ESP-NOW transport (dual UART/ESP-NOW), MAC-ACK failure
    tracking, RSSI monitoring, HB heartbeat parsing, SET command throttling
    - tes_sm: fault immediately on PSU disconnect during CHARGING; fix
    enter_fault() psu_current_target from 5A to 0A
    - led_driver: brief red flash every 5s when ESP-NOW paired but not connected
    - display_svc: PSU status menu item (transport, RSSI, fail reason)
    - network_svc: psu_transport/psu_has_peer/psu_rssi/psu_fail_streak in /status
    - web UI: PSU status row with RSSI-based colour coding
    - config_svc: psu_transport + psu_mac (paired peer MAC) NVS keys
    - main: init ESP-NOW tran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
    [config_svc.c, led_driver.c, main.c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]
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2026-05-18 Fix ESP-NOW pairing: send TES_HELLO reply and align to ch1
    Two bugs prevented successful pairing with LianMing PSU:
    1. After receiving PSU_HELLO, TES never sent a reply — PSU learns
    TES MAC from the Src MAC of the first unicast it receives, so
    without this reply PSU can't add TES as a peer or send telemetry.
    Fix: send "TES_HELLO\n" unicast to PSU immediately after pairing.
    2. PSU AP is fixed on WiFi channel 1. TES in STA mode follows the
    router channel (e.g. ch6), so PSU broadcasts were never received.
    Fix: call esp_wifi_set_channel(1) at the start of the pairing window.
    [psu_driver.c]
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2026-05-18 Fix auto-start stale CAN data fault and add 15A current guard
    - task_tes_sm.c: clear vehicle_status/vehicle_params on IDLE→PARAM_EXCHANGE
    transition to prevent fault_flags accumulated during IDLE broadcast period
    from triggering false FAULT in run_monitoring() during CHARGING
    - tes_sm.c: gate auto-start trigger, VP relay, and IDLE broadcast on
    max_current_01a ≤ 150 (15.0 A); auto-start is not safe above 15A
    - index.html: disable auto-start checkbox and show warning when max
    current > 15A; warning clears when current is reduced to ≤ 15A
    [task_tes_sm.c]
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2026-09-10 WIP: bug-fix pass, charge curve/log, device identity, fault rework
    KNOWN BROKEN: pressing START crashes and reboots the device. Do not merge.
    This is pushed to dev only so the work can be continued on another machine.
    See the handover notes for the debugging plan.
    Bug fixes from a full-firmware review (none vehicle-tested yet):
    - event_bus MAX_SUBSCRIBERS 4 -> 8. There were five subscribers, so with MQTT
    enabled the last one got a NULL queue and panicked.
    - enter_fault/ending/emergency now set state_start_ms themselves. The
    run_monitoring paths never did, so FAULT lived a single tick and ENDING
    skipped waiting for the vehicle contactor.
    - state_names[] order matched to tes_state_t; it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
    [adc_driver.c, config_svc.c]
2026-09-10 Fix task_can_rx stack overflow when START is pressed
    按下 START 立即當機重開，實車測試時穩定重現。序列埠訊息是
    `***ERROR*** A stack overflow in task can_rx has been detected.`
    觸發鏈：b793cf3 在 task_can_rx 的迴圈加了 can_driver_service()。按下 START 後
    狀態機開始送 0x508/0x509，匯流排若收不到 ACK，TWAI 進入 error-passive，
    TWAI_ALERT_ERR_PASS 觸發，於是在這個只有 2048 bytes 的任務裡執行 ESP_LOGW ——
    esp_log 的 vprintf 一次就要 1KB 以上，直接把堆疊打穿。
    改動前 task_can_rx 熱路徑幾乎不 log，2048 才夠用。
    實測 watermark：修正前只剩 52 bytes，改為 4096 後閒置 2100 bytes、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
    [main.c]
2026-09-10 Fix dangling task handle from spawn/unregister race
    task_monitor 在開機約 12 秒後 LoadProhibited 重開機（EXCVADDR=0x00000000），
    症狀是對已釋放的 TCB 解參考。
    競態成因：spawn() 是先 xTaskCreate、後把 handle 登記進 g_tasks。但所有任務的
    優先權都高於 app_main（預設 1）且未綁核，xTaskCreate 一回傳，新任務可能已經在
    另一顆核心上跑完。會自我刪除的任務（mqtt 未設定、ota/log 訂閱失敗時）於是在
    自己還沒被登記時就呼叫 g_task_unregister_self()，掃不到而空手返回；等 app_main
    回來，反而把一個已失效的 handle 寫進表裡。之後 task_monitor 每 10 秒對它呼叫
    uxTa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
    [main.c]
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2026-09-10 Harden MQTT: TLS support and an opt-out for remote control
    MQTT 是這個專案唯一會跨越網際網路的介面，而目前的設定等於把充電器的控制權
    公開放在網路上：
    - 網頁 UI 推薦 broker.hivemq.com（免帳號的公開 broker）
    - topic 是 tes/<device_id>/cmd，device_id 只是 MAC 後 3 bytes
    - 收到 {"cmd":"start"} 就直接送進 g_btn_event_queue
    而且對方根本不需要猜 topic —— 公開 broker 允許萬用字元訂閱，
    tes/+/status 一次就能列出所有在線裝置的 device_id 與即時狀態，
    再對著對應的 cmd topic 下指令。這是網際網路範圍的暴露，不需要接近現場。
    三項改動：
    1) 支援 mqtts://。原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
    [config_svc.c]
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2026-09-12 Generate the V1.3 schematic from its netlist instead of importing it
    The Altium round-trip out of EasyEDA Pro did not import cleanly, so the
    schematic is built directly from the data we already trust: the per-pin
    netlist that tools/eda_export.py pulls out of the .eprj.
    That turns out to be the better path anyway. Hand-redrawing 73 components
    and 253 connections has no way to prove it is right; a generated schematic
    can be exported back to a netlist and compared against the source. It does:
    218 connections, zero missing, zero wrong, zero extra. ERC is clean at 0
    violations.
    Connectivity is by net label rather than drawn wires, so components can be
    rearranged in the GUI without breaking anyt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
    [TES_Controller.kicad_sch]
2026-09-12 Lock the buck module's mounting holes, and fix U10's description
    U10 is a DG301 5.0 mm screw terminal, not a footprint for the 120 V buck
    module — the module is a separate board stacked above this one on standoffs
    and wired in. The previous description in the lock file was wrong.
    The module's real footprint on this PCB is four holes, which the extractor
    was not looking for: they are circular fills on the Multi-Layer, not pads.
    Four M3 holes on a 48.5 x 24.0 mm rectangle, now in mechanical_lock.json
    alongside the component positions. Move them and the module no longer bolts
    down.
    Two consequences for the re-layout, recorded here so they are not
    rediscovered later: the area those holes enc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
    [TES_Controller.kicad_sch]
2026-09-12 Recover the four module wire pads the extractor was silently dropping
    The 120 V buck module's wires land on four pads drawn directly in copper,
    not on components. PAD_NET only describes component pads, so those four
    never appeared in bom.csv or netlist.txt, and I concluded from their absence
    that the board had no landing point for the module's 12 V output. It has had
    one all along, on every revision back to V1.
    Two things that follow were wrong and are now corrected:
    - The 120 V net is not a two-pad stub. It runs 63.9 mm of 1.27 mm track on
    the bottom layer from U10 across to the module's IN pad, plus 22.6 mm of
    0.25 mm feeding the divider. GND_BACK runs alongside it for 62.1 mm. That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
    [TES_Controller.kicad_sch, bom.csv]
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2026-09-12 Import V1.3's actual PCB and bring the 120 V clearance up to IPC-2221B
    kicad-cli's --format auto detects EasyEDA Pro project zips, even though the
    format is not in its documented list. That imports V1.3 complete: 77
    footprints, 545 tracks and vias, the outline, the mounting holes. Starting
    from a board that already works beats re-routing 49 nets from nothing.
    pcb_import.py normalises the import to match the verified schematic —
    designators, net names, and references for the four wire pads, which arrive
    as unnamed footprints. The backup zip is from May and trails the current
    .eprj by exactly two pads: C20.1 and U5.8 were still on VDD33 before the
    ADS1115 supply moved to 5 V. Those are corr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
    [TES_Controller.kicad_pcb]
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2026-09-12 Move routing off the bottom layer to get a real ground plane
    V1.3 put 649 mm of copper on the bottom — 120 V, 12 V, all three gate
    drives, CAN, USB — so the bottom was never a ground plane, and ground had to
    be patched together on top instead. With 62 SMD footprints up there that
    patch came out as two dozen islands, which is why every refill stranded a
    different handful of decoupling capacitors.
    What makes the fix possible is the buck module's reserved area: 48.5 x 24 mm
    with no components, restricting height but not copper, sitting between the
    ESP32 above and the drivers and connectors below. At 0.4 mm pitch it takes
    about 120 parallel tracks and only 18 nets need to cross.
    | | before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
    [TES_Controller.kicad_pcb]
2026-09-13 Finish routing the restructured board and clear everything but courtyards
    Every net is connected now — DRC reports zero unconnected items — and errors
    are down from 63 to 21, all of them courtyard overlaps.
    The fine-pitch pins were the hard part. U5 is an MSOP-10 rotated 90 degrees:
    0.5 mm pitch leaves 0.22 mm between pads, so nothing can pass between them
    and every pin has to escape past the end of its own pad. The grid router
    cannot express that — dilation seals the pad in on all sides — so those pins
    get a two-stage route: a short escape segment checked against real geometry,
    then the maze from the escape point onward.
    Two smaller router gaps showed up the same way. SCL failed a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
    [TES_Controller.kicad_pcb]
2026-09-13 Clear the last DRC errors: zero errors, zero unconnected
    Two placements actually needed moving, and neither was V1.3's fault — both
    were mine. D10's pad sat directly on W2's wire pad, same net so not a short,
    but nothing could be soldered to that pad afterwards. R21 overlapped CN2's
    courtyard by 1.5 mm, deep enough that the resistor risked sitting under the
    connector housing. Both moved 2 mm and their nets re-routed.
    The remaining 20 courtyard overlaps are not assembly problems. What decides
    whether two parts fit is the physical gap between their pads, and those
    measure 0.356 to 3.671 mm — the tightest is well past JLCPCB's 0.2 mm
    minimum, and V1.1 and V1.2 shipped with this placement.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
    [TES_Controller.kicad_pcb]
2026-09-13 Make the board and schematic agree on one footprint library
    The board's footprints pointed at a library called TES_Contro-easyedapro
    that does not exist, while the schematic assigned TES:. That is not just a
    warning — the first time anyone runs "Update PCB from Schematic" in the GUI,
    all 73 footprints get swapped and the routing goes with them.
    Fixing it turned up something I had got wrong earlier. easyeda2kicad works
    from LCSC part numbers, so it skips generic parts, and I concluded the 5 mm
    LED, the 2.54 mm headers and the solder jumper had no footprints and drew
    them myself. The EasyEDA Pro project zip has them all along; they came in
    with the board import. The two versions differ —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
    [TES_Controller.kicad_pcb, TES_Controller.kicad_sch]
2026-09-13 Move the reference designators that were printed over pads
    Silkscreen over a pad does not print — the solder mask opening takes it —
    so the designator is simply missing where you need it while hand-soldering.
    W1 through W4 and D9 had theirs sitting on their own pads; all five moved
    1-2 mm clear.
    The seven that remain are footprint outlines crossing their own pads, which
    is drawn into the footprints themselves. Left alone, as are the 51
    silkscreen-to-edge warnings: those are the edge connectors and the ESP32
    module, whose outlines are meant to run off the board and get trimmed in
    fabrication.
    [TES_Controller.kicad_pcb]
2026-09-13 Split R10 so no resistor sits above its rated voltage
    R10 is a single 0603 carrying the top half of the 120 V sense divider. A
    0603's rated working voltage is 75 V; at 120 V input it sees 116 V, half
    again over the limit. This is not thin margin, it is continuous operation
    out of spec, and the failure mode is quiet: the resistor drifts upward,
    which lowers the divided voltage, so the charger reads the pack as lower
    than it is and reports that to the vehicle.
    118k + 115k + 115k comes to exactly 348k, so the divider ratio is unchanged
    and AIN0 still sits at 4.0000 V at 120 V input — no firmware constant moves.
    All three are E96 values. Each drops 38-39 V, giving 1.9x margin on the 75 V
    rati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
    [TES_Controller.kicad_pcb, TES_Controller.kicad_sch]
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2026-09-14 Redraw the schematic the way it was drawn in EasyEDA
    The generated schematic was correct but unreadable — everything was
    arranged by the generator, so nothing sat where the author left it.
    This rebuilds it from the original .esch: the same 73 components at the
    same coordinates, the same 12 block titles and grouping boxes, the same
    wires.
    Getting the pins to land took working out what easyeda2kicad actually
    does, which is: nothing. It copies EasyEDA's pin coordinates straight
    into the KiCad symbol library, and KiCad's library Y axis points the
    other way — so every symbol comes out upside down. tools/easyeda_symbols.py
    checks this pin by pin against the original project file (25 of 25
    sym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
    [TES_Controller.kicad_sch]
2026-09-14 Keep the AO3400A pin swap that the EasyEDA design relied on
    LCSC's SOT-23-3 footprint for C20917 numbers pads 1 and 2 the opposite
    way round from JEDEC TO-236: viewed from the top, 1 -> 2 -> 3 runs
    clockwise, so the pad stamped "1" sits under the chip's pin 2. Every
    other package in this library runs counter-clockwise, and each of those
    checks out against its own datasheet — TJA1051 pin 1 is TXD, AMS1117
    pin 1 is GND, USBLC6 pin 2 is GND, and Q4's AO3401A takes its gate on
    pad 1 with an unmodified symbol.
    The EasyEDA design compensated by drawing Q1-Q3 with a symbol whose
    pins 1 and 2 are swapped, which is why the board works. The migration
    dropped that: the generated library carries LCSC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
    [TES_Controller.kicad_sch]
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2026-09-14 Record the V1.3 change set, and pause before it reaches the board
    Three changes are decided and carried in the schematic and library; none of
    them are on the PCB yet. Recording the split explicitly so the next session
    does not mistake it for an unfinished edit:
    * U13 24C02S EEPROM (LCSC C18723540) with C30 decoupling — stores the board
    revision so one binary can serve V1.3 and the 30.000-divider units in the
    field. WP to GND, firmware decides when to write.
    * D10 becomes SMBJ12A, the part D3 already uses, and moves out from under the
    buck module. Lower clamp (19.9 V against 21.5 V) and no new part number.
    * R35, a 10 k that divides Q4's gate drive. Q4 sat at exactly its ±12 V
    abs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
    [TES_Controller.kicad_sch]
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2026-09-24 Talk to the power node over link protocol v2
    psu_driver now speaks the protocol defined in the new PSU-Link
    submodule: CRC-checked lines, integer 0.01 V / 0.01 A fields, a
    capability message, sequenced setpoints with ACK, and a status message
    that doubles as the heartbeat. The LianMing PSU Controller uses the
    same submodule, so the two ends cannot drift apart. It is a separate
    repository rather than part of TES-Protocol because this link never
    touches the vehicle; TES-Protocol stays the TES-0D-02-01 CAN protocol.
    The state machine is untouched. psu_status_t keeps its first five
    fields with their old meaning, so task_tes_sm, display_svc and
    network_svc compile unchanged; node identity, the l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
    [psu_driver.c]
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

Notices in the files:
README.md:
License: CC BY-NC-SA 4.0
